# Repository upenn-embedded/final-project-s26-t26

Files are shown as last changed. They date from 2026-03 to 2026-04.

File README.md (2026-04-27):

Review Assignment Due Date (https://classroom.github.com/a/-Acvnhrq)

# Final Project

**Team Number:** Team 12

**Team Name:** AAA Battery

| Team Member Name | Email Address |
| --- | --- |
| Abhay Agarwal | abhaya@seas.upenn.edu  |
| Ashwin Ranjan | aranjan@seas.upenn.edu |
| Arnuv Batra | avbatra@seas.upenn.edu |

**GitHub Repository URL:** https://github.com/upenn-embedded/final-project-s26-t26.git

**GitHub Pages Website URL:** [for final submission]*

## Final Project Proposal

### 1. Abstract

Our project is a dual-axis solar tracker that automatically orients a solar panel toward the brightest light source and maximizes the energy harvested from it. Four light sensors detect the sun's direction, two servos aim the panel, and an MPPT algorithm tunes a buck converter to extract peak power. An ESP32 streams data to a live web dashboard. The system demonstrates measurable efficiency gains over a fixed panel.

### 2. Motivation

Fixed solar panels lose significant energy throughout the day as the sun moves across the sky - often capturing only 60–70% of available energy compared to a panel that tracks the sun. Adding MPPT further increases efficiency by ensuring the panel operates at optimal voltage regardless of changing light and temperature conditions.

This project is interesting as it will combine analog sensing, real-time control, power electronics, and IoT on the ATMega. The result is a fully functional miniature solar energy system that is optimized to maximize power output.

### 3. System Block Diagram

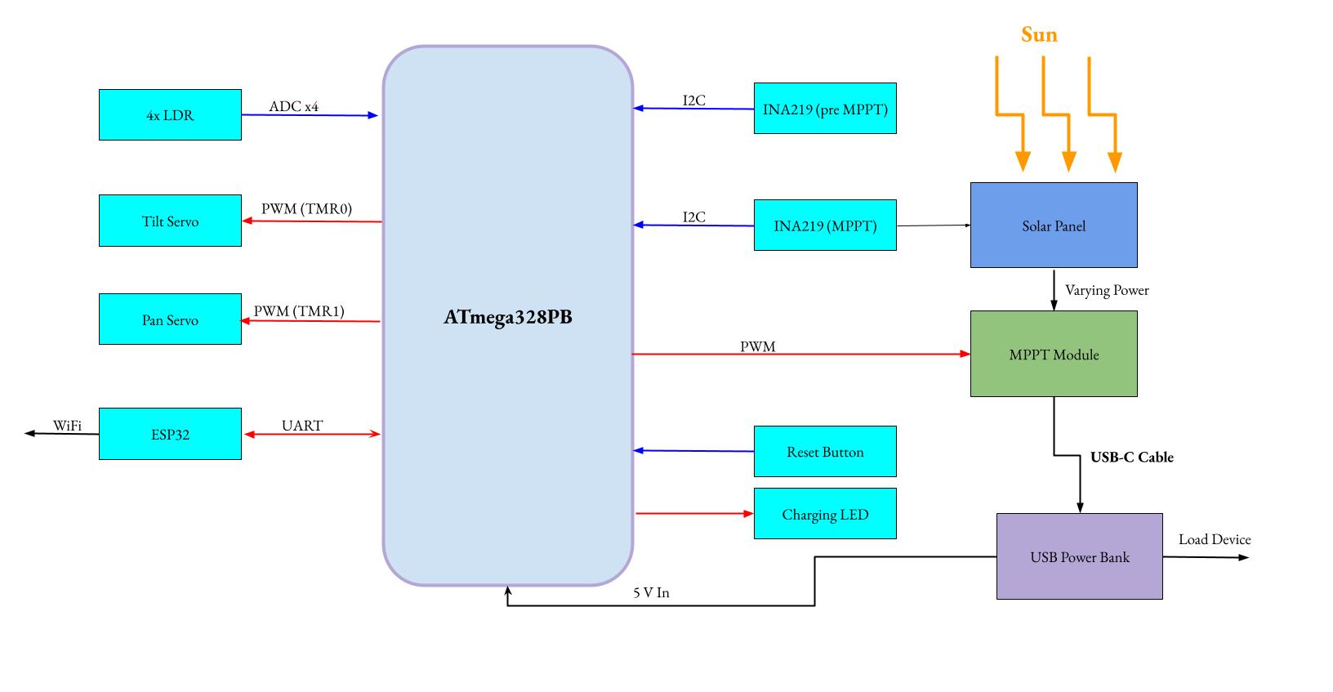
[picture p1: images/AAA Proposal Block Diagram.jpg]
System Block Diagram


### 4. Design Sketches

The LDR quadrant divider is the most critical design feature — a small cross-shaped wall between the four LDRs that creates shadow differences when the panel is off-angle, enabling the tracking algorithm to determine direction.
The pan-tilt bracket and base enclosure will both be 3D-printed, allowing us to customize the mount to fit our specific solar panel and servo arrangement.

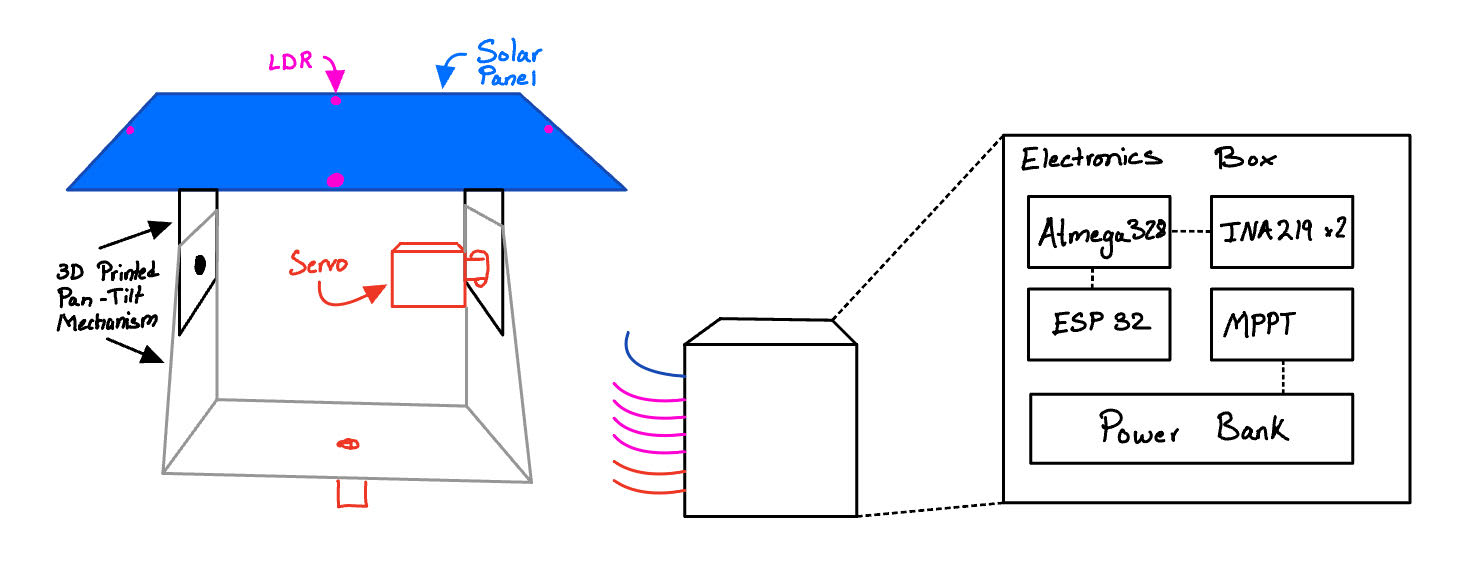
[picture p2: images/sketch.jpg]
Design Sketch


### 5. Software Requirements Specification (SRS)

**5.1 Definitions, Abbreviations**

Here, you will define any special terms, acronyms, or abbreviations you plan to use for hardware

LDR = light dependent resistor

MPPT = Maximum Power Point Tracking (for solar panels, basically constantl adjusting to optimize the voltage/current delivered for maximum power output)

**5.2 Functionality**

| ID | Description |
| --- | --- |
| SRS-01 | The system will sample the 4 LDRs via the ADC at a minimum frequency of 10 Hz. |
| SRS-02 | The firmware will implement a deadband filter algorithm to prevent servo jitter when the calculated light intensity error between opposing LDRs is below a certain threshold. |
| SRS-03 | The system will update the IoT dashboard without major latency (<3 seconds) with current tracking status, MPPT values, and error margins. This will be achieved with a ESP32 coprocessor acting solely as a serial-to-Wi-Fi bridge. |
| SRS-04 | The MCU will utilize hardware timers to generate a stable 50Hz PWM signal for servo actuation without blocking the main execution loop. |
| SRS-05 | Upon a physical button press interrupt, the system will reset the servos to a default home position within 2 seconds. |

### 6. Hardware Requirements Specification (HRS)

**6.1 Definitions, Abbreviations**

Here, you will define any special terms, acronyms, or abbreviations you plan to use for hardware

**6.2 Functionality**

| ID | Description |
| --- | --- |
| HRS-01 | The solar tracking mechanism will physically rotate at least 45 degrees horizontally (pan) and 45 degrees vertically (tilt). |
| HRS-02 | The LDRs accurately capture the difference in light between specific locations on the panel, which is then used to adjust the panel tilt and pan accordingly. |
| HRS-03 | An off-the-shelf MPPT module OR our own custom hardware using a buck/boost converter + PWM from the ATMega will safely regulate the charging voltage from the solar panel to the energy storage system. |
| HRS-04 | The system should charge a battery bank via USB-C, and be able to clearly show whether power is being generated via an LED. |

### 7. Bill of Materials (BOM)
What major components do you need and why? Try to be as specific as possible.:

We need the 2 processors (ATMega and ESP 32). The ATMega is for general communication and interfacing and will be where our computing is done. The ESP32 serves as a port to serve the data we recieve, after processing, to the cloud via wifi. 

We use 4 LDRs to take brightness readings at each corner, and for each of them we read the current that passes through them as a measure of how bright/dim the area is, so we can angle our solar panel accordingly. 

The solar panel is used to actually capture power, and it's mounted on 2 micro stepper motors to control its pan (horizontal) and tilt (vertical) axes. 

A current/voltage sensor is used to read the output power of the solar panel, and the power bank is used to store the generated electricity. 

The details of all these can be found in the sheet below.

[BOM Sheet](https://docs.google.com/spreadsheets/d/1A1eUAg9dwYdbk0ykns5I-RBsm5lOC9emmNqb9aPvp44/edit?usp=sharing)

### 8. Final Demo Goals

A movable desk lamp will simulate the sun. We move the lamp to different positions and the panel visibly tracks it in real time. A laptop next to the device will display the live web dashboard showing power output and panel orientation.
The main constraints are WiFi access in the lab for the ESP32 dashboard and a power outlet for the desk lamp. The device itself runs on its solar panel and battery.

### 9. Sprint Planning

| Milestone  | Functionality Achieved | Distribution of Work |
| --- | --- | --- |
| Sprint #1  | Finalize BOM, order parts, and begin 3D printing the gimbal/baffle. Set up the bare-metal C toolchain. Write and test the ADC polling and PWM timer code. Connect the servos and test movement. | Arnuv: BOM finalization, 3D print gimbal/baffle. Abhay: ADC polling & LDR voltage divider setup, toolchain config. Ashwin: PWM timer drivers & servo connection/testing. |
| Sprint #2  | Implement the LDR-based tracking algorithm with deadband filtering and verify servo response to differential light readings. Begin MPPT module wiring and validate solar panel charging into the battery bank. Set up UART communication between ATmega and ESP32 and confirm serial data passthrough. Start scaffolding the web dashboard on the ESP32 side. | Arnuv: MPPT module wiring, solar panel integration, charging validation. Abhay: UART bridge between ATmega & ESP32, begin ESP32 dashboard scaffolding. Ashwin: Tracking algorithm with deadband filter, servo closed-loop testing. |
| MVP Demo | Integrate LDR inputs with servo outputs to achieve basic tracking. Wire the MPPT module for basic charging. Integrate the I2C current sensors. Write the UART bridge firmware and establish the ESP32 web dashboard. | Arnuv: I2C INA219 sensor integration, mechanical assembly refinement, home-position button interrupt. Abhay: Live dashboard displaying tracking status & MPPT values. Ashwin: Full tracking loop integration. |
| Final Demo | Final hardware integration, code optimization, and rigorous testing for the final demonstration. | All: End-to-end system testing, debugging, demo prep. Arnuv: Mechanical fit & finish, LED power indicator integration. Abhay: Dashboard polish & latency validation. Ashwin: Tracking accuracy tuning & code cleanup. |

**This is the end of the Project Proposal section. The remaining sections will be filled out based on the milestone schedule.**

## Sprint Review #1

### Last week's progress

This week we built a simplified single-axis solar tracker demo to validate our core tracking algorithm before integrating into the full dual-axis system. We wrote the code in demo.c and pushed it to the repo.
The demo uses two LDRs connected to PC0 and PC1 to sense light direction. We configured Timer1 to generate 50Hz PWM on PB1 for servo control. The tracking algorithm compares the two LDR readings and moves the servo toward the brighter side. We also implemented a deadband filter to prevent the servo from jittering when the light levels are nearly equal.

During development we ran into a few issues. The board kept resetting whenever the servo moved, which we traced to the servo drawing too much current and causing a voltage drop.

Once we fixed that, we discovered the servo was drifting more in one direction even when the light was centered. This was because our two LDRs have slightly different responses, so we added UART printing to read the raw ADC values. Next time we will calculate a calibration offset to add to our code

### Current state of project
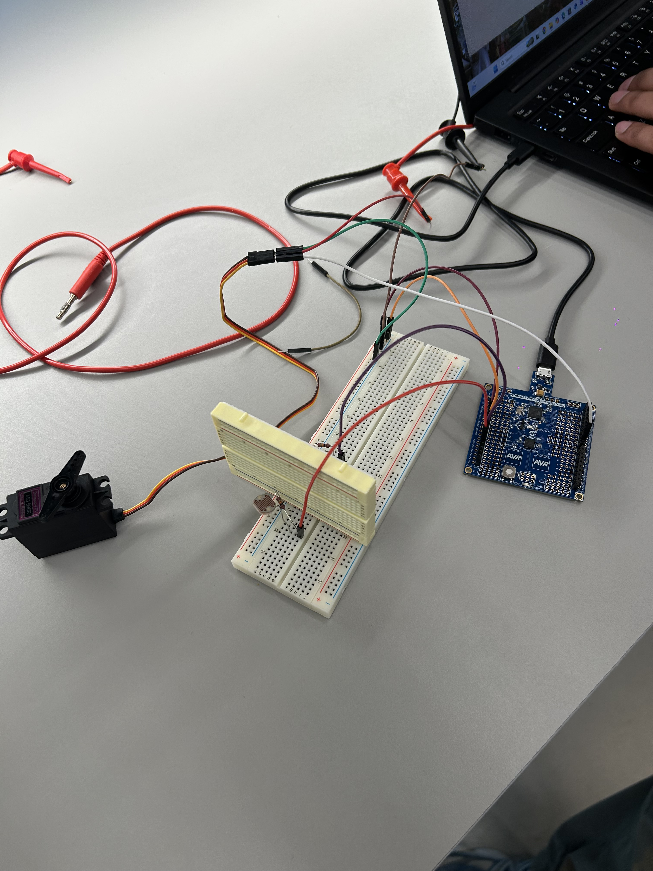
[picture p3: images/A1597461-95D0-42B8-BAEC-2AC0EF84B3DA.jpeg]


The single-axis tracking demo is working. The servo successfully follows a light source using two LDRs. This validates our tracking algorithm and servo control code, which we can now duplicate for the second axis. The 3D printed gimbal mount is being designed. We have also ordered the needed parts.

### Next week's plan

Abhay will set up the INA219 sensors and ESP32 communication, around 5 hours. Done when sensor data displays on the ESP32.

Ashwin will add the second servo and tune the tracking, around 4 hours. Done when the panel tracks light in both axes smoothly.

Arnuv will 3D print the gimbal mount and LDR divider, around 6 hours. Done when everything is mounted and moves freely.

## Sprint Review #2

### Last week's progress

Abhay completed the INA219 current/voltage sensing setup. The INA219 is now communicating over I2C and providing accurate power readings from the solar panel. The driver code has been written and pushed to the repo.

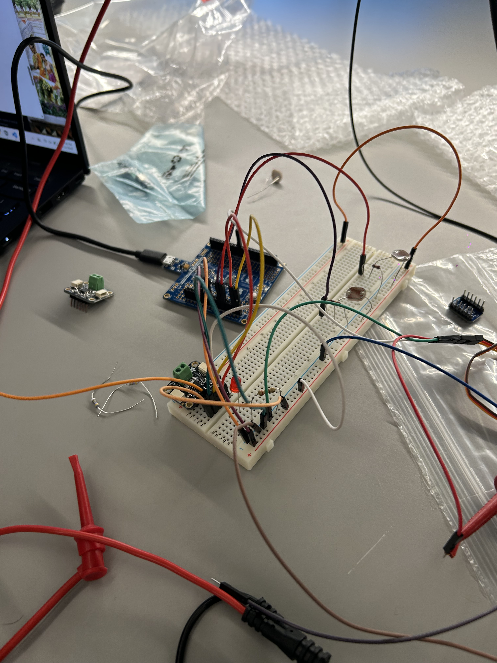
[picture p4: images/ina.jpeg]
INA219 Sensor


Ashwin got the ESP32 Feather working and set up a local web server that pulls all sensor data for the live dashboard. He also sent off the prints for the remaining mechanical housing parts.

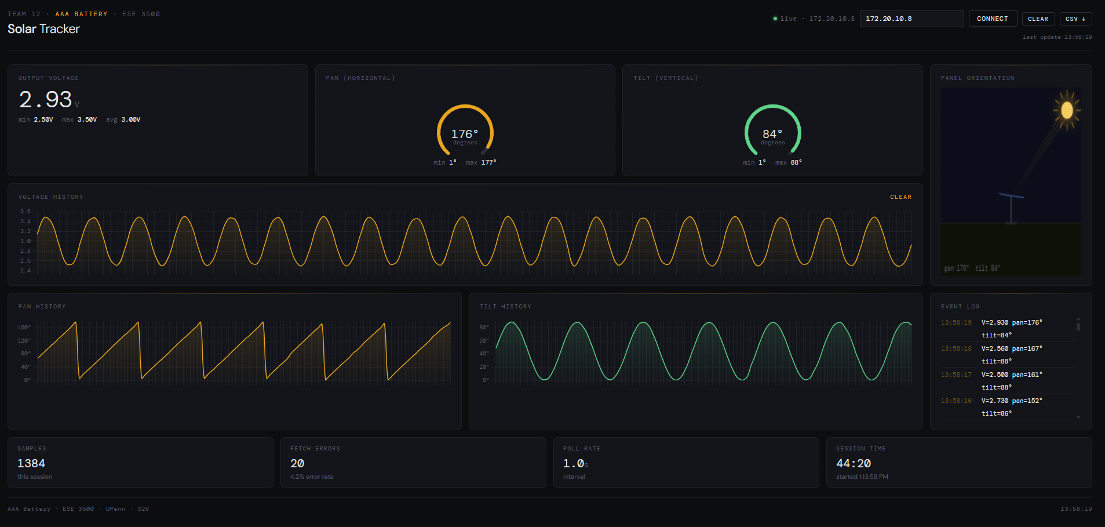
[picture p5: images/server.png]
Web Server Dashboard


Arnuv printed the mechanical parts for the gimbal and is assembling the full pan-tilt mechanism with the servos mounted. He also CADed and printed a solar panel mount.

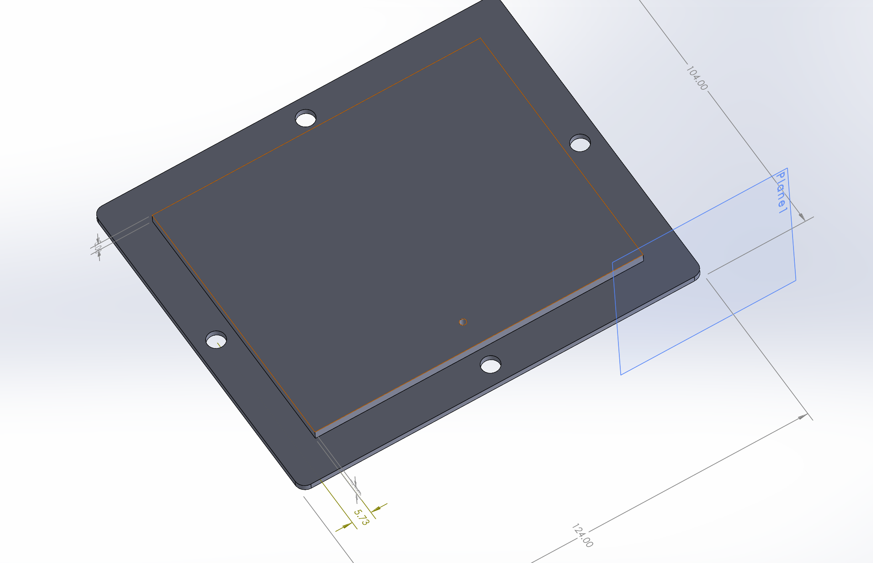
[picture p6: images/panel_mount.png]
Solar Panel Mount


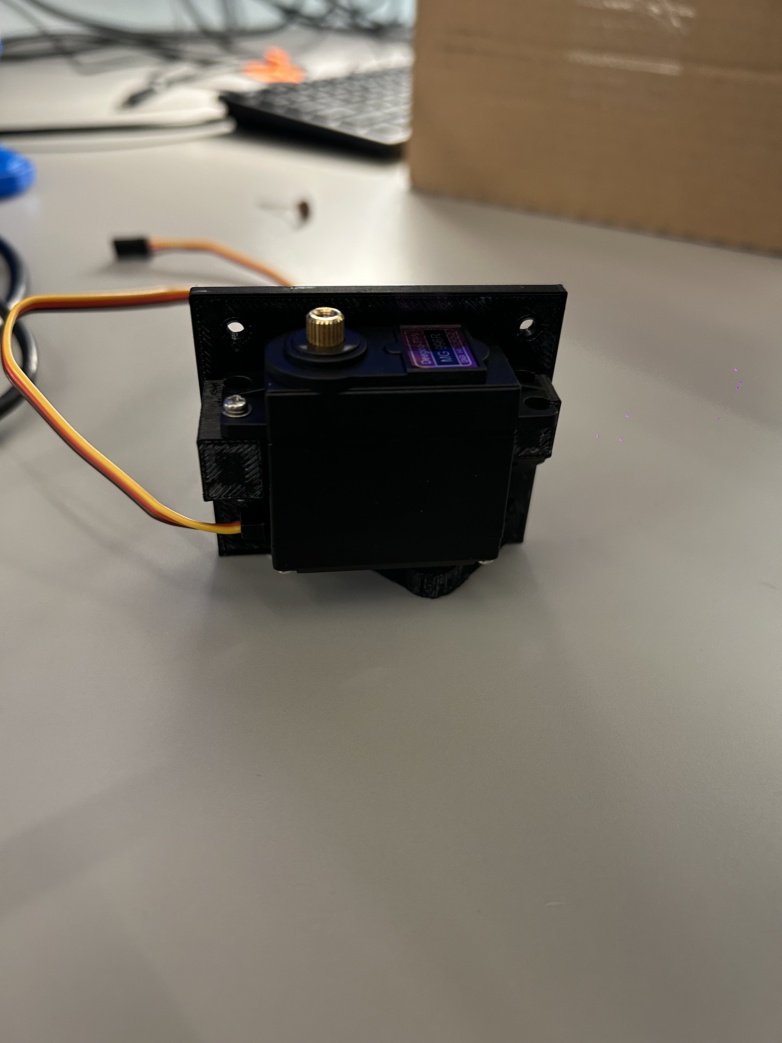
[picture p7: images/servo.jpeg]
Servo Assembly


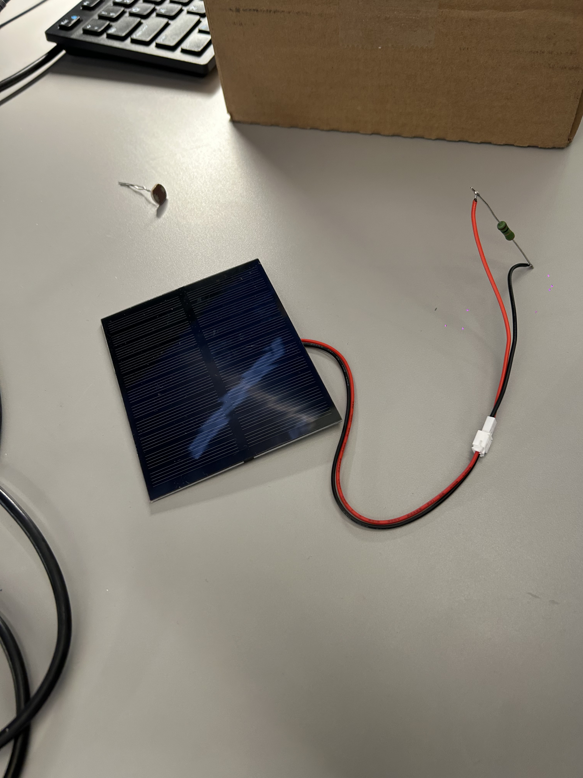
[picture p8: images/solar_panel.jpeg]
Solar Panel


### Current state of project

The core sensing and data pipeline is coming together. The INA219 is reading solar panel power output, the ESP32 is hosting a live dashboard over Wi-Fi, and the mechanical gimbal is being assembled with the 3D-printed parts. The main integration work remaining is connecting the ATmega tracking loop to the ESP32 dashboard via UART and mounting the solar panel on the completed gimbal.

### Next week's plan

Abhay will integrate the INA219 readings into the UART data stream to the ESP32, around 4 hours. Done when live power data appears on the web dashboard.

Ashwin will finalize the full tracking loop integrating both axes with the ESP32 data display, around 5 hours. Done when the dashboard shows real-time tracking status and power output.

Arnuv will complete the mechanical assembly and mount the solar panel and LDR divider onto the gimbal, around 5 hours. Done when the full system is physically assembled and the panel can move freely on both axes.

## MVP Demo

### 1. System block diagram & hardware implementation

System Block Diagram

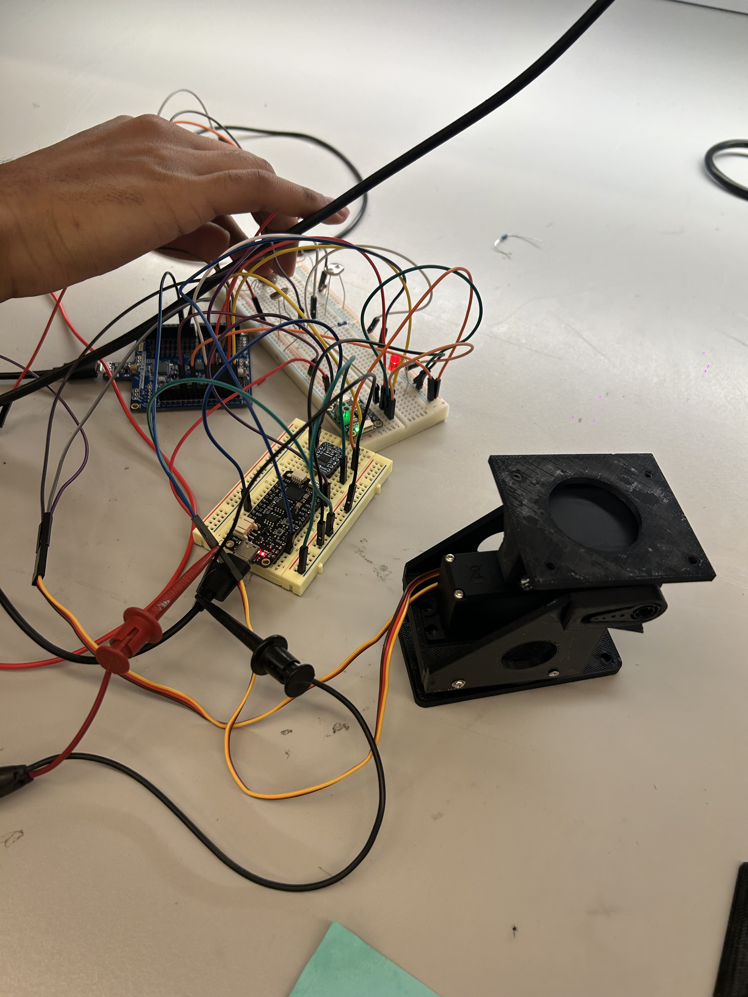
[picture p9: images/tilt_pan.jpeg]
Assembled pan/tilt tracker


The ATmega328PB is the main MCU. It runs the tracking loop, reads the four LDRs through its ADC, drives both servos with hardware-timer PWM, and talks to the INA219 over I2C. It then ships the full telemetry packet (voltage, current, power, pan, tilt) up to the ESP32 Feather over UART. The Feather acts as a serial-to-Wi-Fi bridge and parses the UART frames and hosts a local HTTP server that shows the latest readings. 

Power-wise, the solar panel goes through an INA219 sensor, then into the MPPT/buck stage, then into a USB-C power bank. A "power OK" LED will be wired off the panel-side rail to show when the panel is generating.

### 2. Firmware implementation

#### Application logic (ATmega, [Code/main.c](Code/main.c))

- Main loop samples four LDRs via ADC, computes horizontal and vertical error from opposing pairs, applies a deadband, and nudges the pan/tilt servo targets. Servo duty cycles are written directly to the Timer1 compare registers so the 50 Hz PWM never blocks the main loop.
- Polls the INA219 every loop iteration and packs voltage/current/power plus current pan/tilt into a CSV line sent over UART at 9600 baud.
- Home-position button routed to an external interrupt pin, so the ISR sets a flag that the main loop picks up to drive both servos back to center.

#### ATMega Code

- [Code/i2c.c](Code/i2c.c) / [Code/i2c.h](Code/i2c.h) — I2C master driver for the ATmega: start/stop, byte read/write, repeated-start, no Arduino Wire dependency.
- [Code/ina219.c](Code/ina219.c) / [Code/ina219.h](Code/ina219.h) — INA219 driver built on top of our I2C driver. Configures the calibration register and gets voltage and current readings.
- [Code/uart.c](Code/uart.c) / [Code/uart.h](Code/uart.h) — UART TX/RX driver used for debug prints and the ESP32 server.
- [Code/demo.c](Code/demo.c) — the Sprint #1 single-axis validation demo that we generalized into the dual-axis tracker in [Code/main.c](Code/main.c).

#### ESP32 Code ([Code/ese3500_uart.ino](Code/ese3500_uart.ino))

- Reads the UART CSV frames and outputs a JSON. Also serves the server [index.html](index.html).

### 3. Demo

> **https://drive.google.com/file/d/1Zr529B0K1XDM-7jDKDU-3Q6FYsO6Z7r6/view?usp=sharing**

Live demo flow: point a desk lamp at the panel → the gimbal tracks toward it on both axes → the dashboard updates voltage, current, and power in real time.

### 4. SRS status & validation

<!-- markdownlint-disable MD060 -->

| ID | Description | Status | Validation |
| --- | --- | --- | --- |
| SRS-01 | Sample 4 LDRs via ADC at >=10 Hz | Achieved | Main loop has an inbuilt delay of 100ms, so each LDR samples at 10 Hz. |
| SRS-02 | Deadband filter to prevent servo jitter | Achieved | With panel centered, servos hold still; logged UART error values stay inside the deadband. |
| SRS-03 | IoT dashboard updates with < 3 s latency | Achieved | Dashboard polls the ESP32 server data at 1 Hz; measured end-to-end UART-to-dashboard lag is under 3s |
| SRS-04 | Hardware-timer 50 Hz PWM, non-blocking | Achieved | Scoped PB1/PB2 PWM outputs - stable 20 ms period, main loop continues executing during PWM.|
| SRS-05 | Button interrupt resets servos to home within 2 s | Achieved | Button wired to external-interrupt pin; servos return to center on press, well under 2 s.  |

<!-- markdownlint-enable MD060 -->

**How we collected the data:** GPIO-toggle + oscilloscope for ADC and PWM timing (SRS-01, SRS-04); live UART logs captured on the laptop for deadband and latency checks (SRS-02, SRS-03); timer on repeated button presses for SRS-05.

### 5. HRS status & validation

<!-- markdownlint-disable MD060 -->

| ID | Description | Status | Validation |
| --- | --- | --- | --- |
| HRS-01 | Physical rotation >=45 deg pan and >=45 deg tilt | Achieved | Both axes exceed 45 degrees visually - pan is 180 degrees of motion and tilt is ~80. |
| HRS-02 | LDRs capture light differences for tracking | Achieved | Moved a phone flashlight across the LDR array and logged raw ADC values over UART; opposing pairs diverge cleanly.|
| HRS-03 | MPPT / buck-boost regulating charging from the panel | Not achieved | Module is wired on the bench but MPPT tuning against the real panel is still open. |
| HRS-04 | USB-C battery-bank charging with LED power indicator | Partial | LED is mounted; remaining work is wiring the solar-panel rail through to the USB-C output. |

<!-- markdownlint-enable MD060 -->

**How we collected the data:** visual measurement on the physical gimbal (HRS-01); LDR raw ADC logs streamed over UART and cross-checked against the dashboard (HRS-02); INA219 voltage/current on the dashboard while the panel is under lamp (feeds into HRS-03 validation for Final Demo).

### 6. Remaining elements to complete the project

- **Mechanical enclosure** — enclosure base for the electronics is printing but needs fit-and-finish (cable routing, lid, button cutout).
- **GUI / web portal** — the dashboard in [index.html](index.html) is live and charting voltage/current/power/pan/tilt; remaining polish is a dedicated history chart for power and an MPPT efficiency plot once HRS-03 is done.
- **Power path** — finish HRS-04 by routing the regulated panel output through the USB-C charger IC and wiring the "power OK" LED off that rail.
- **MPPT tuning** — sweep the buck converter duty cycle and log power to find the peak (HRS-03).

### 7. Riskiest part remaining

**MPPT (HRS-03).** The tracking, sensing, and dashboard are all solved. The riskiest piece left is getting the buck-converter + MPPT loop to actually hold the panel at its maximum-power point under changing light without oscillating or stalling the panel.

### 8. De-risking plan

- Start with a fixed duty-cycle sweep logged through the INA219, so we can plot a P-V curve for our panel under the lamp and confirm the MPPT is converging to the real peak.
- Implement perturb-and-observe in small duty-cycle steps with a dwell time longer than the INA219 conversion time to avoid chasing noise.
- Fall back to an off-the-shelf MPPT module (already in the BOM) if our custom loop is unstable by the week before Final Demo — this is the explicit "OR" in HRS-03.
- Keep the panel → INA219 → dashboard path as a bench oscilloscope for the MPPT loop, so any regression is visible in real time.

### 9. Questions / help from the teaching team
N/A

## Final Report

Don't forget to make the GitHub pages public website!
If you’ve never made a GitHub pages website before, you can follow this webpage (though, substitute your final project repository for the GitHub username one in the quickstart guide):  [https://docs.github.com/en/pages/quickstart](https://docs.github.com/en/pages/quickstart)

### 1. Video

### 2. Images

### 3. Results

#### 3.1 Software Requirements Specification (SRS) Results

| ID | Description | Validation Outcome |
| --- | --- | --- |
| SRS-01 | The IMU 3-axis acceleration will be measured with 16-bit depth every 100 milliseconds +/-10 milliseconds. | Confirmed, logged output from the MCU is saved to "validation" folder in GitHub repository. |

#### 3.2 Hardware Requirements Specification (HRS) Results

| ID | Description | Validation Outcome |
| --- | --- | --- |
| HRS-01 | A distance sensor shall be used for obstacle detection. The sensor shall detect obstacles at a maximum distance of at least 10 cm. | Confirmed, sensed obstacles up to 15cm. Video in "validation" folder, shows tape measure and logged output to terminal. |
| | | |

### 4. Conclusion

## References

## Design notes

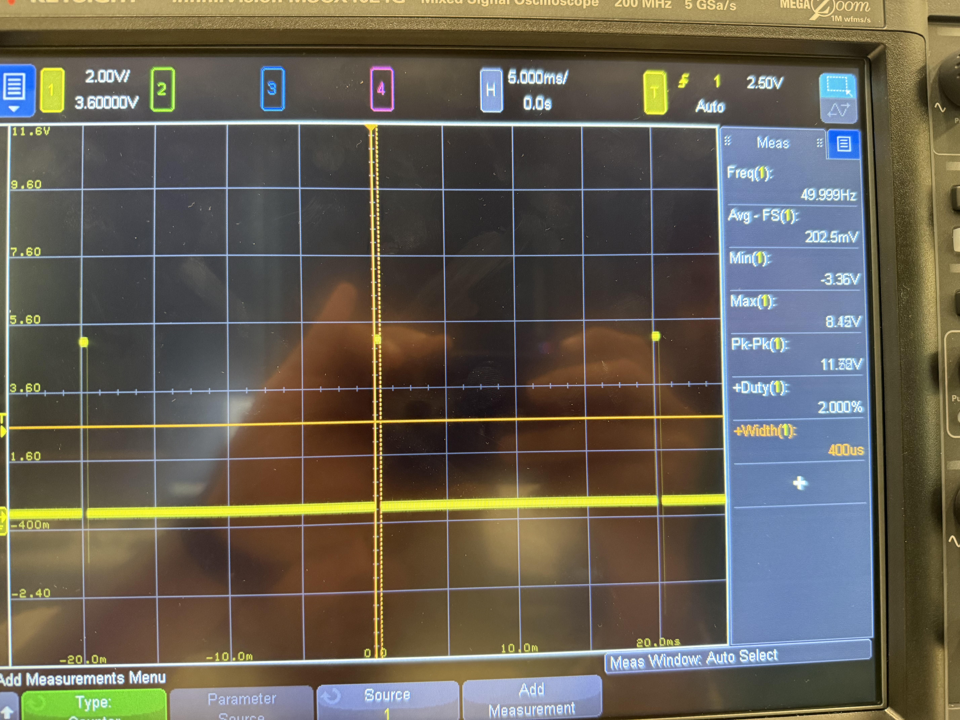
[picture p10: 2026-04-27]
images/min_duty_cycle.jpg

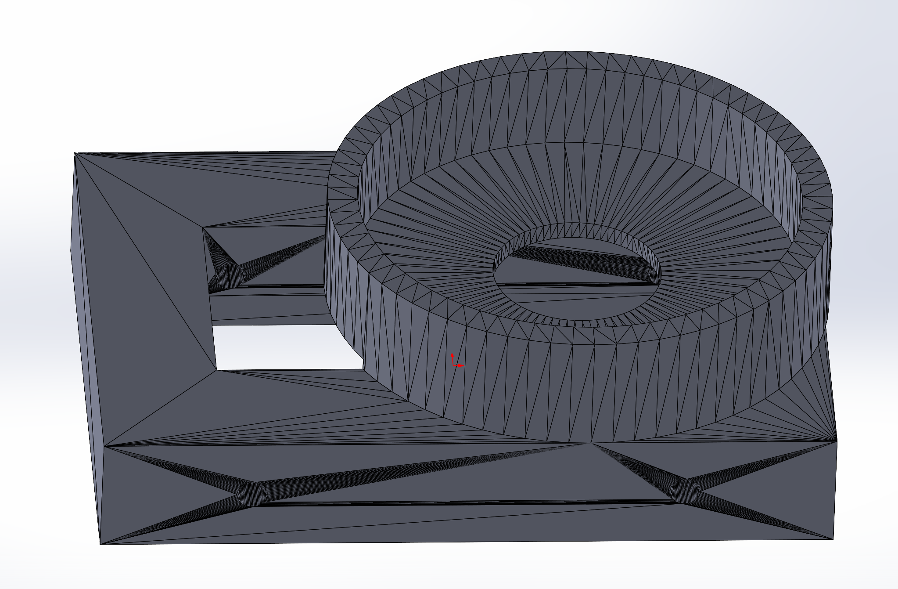
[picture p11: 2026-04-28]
docs/images/cad1.png

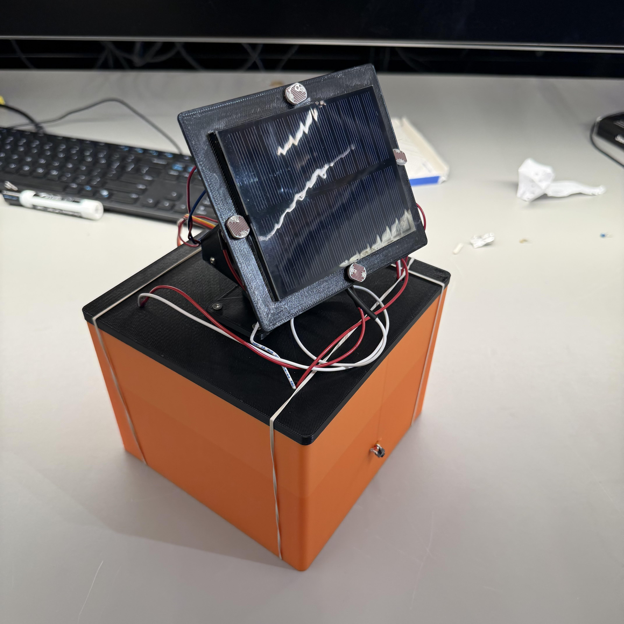
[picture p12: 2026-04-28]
images/final_project.jpg

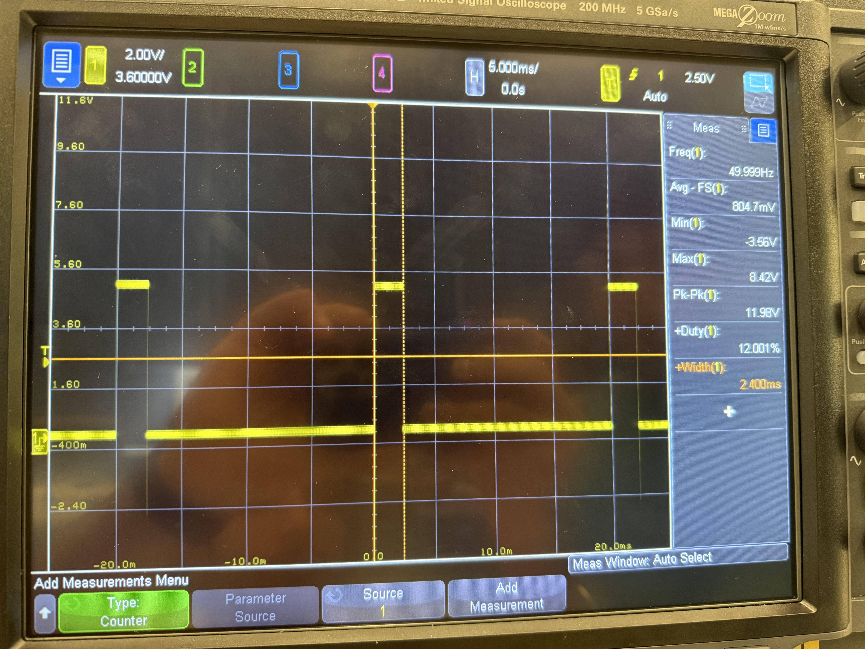
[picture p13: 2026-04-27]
images/max_duty_cycle.jpg

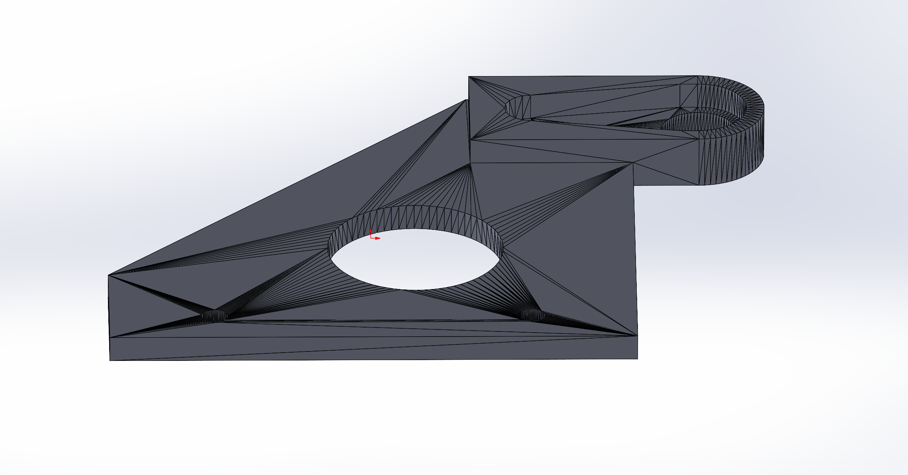
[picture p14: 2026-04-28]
docs/images/cad3.png

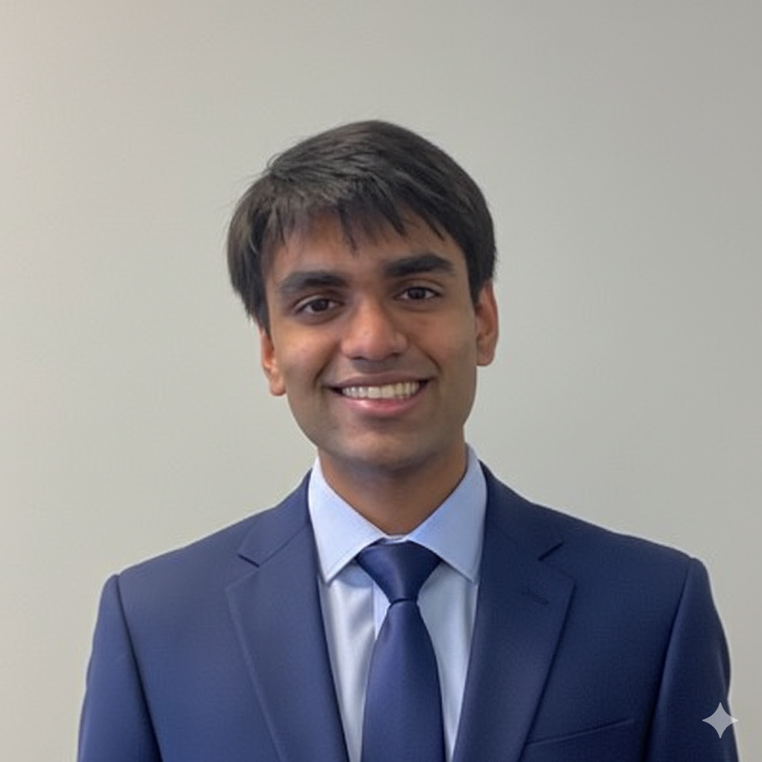
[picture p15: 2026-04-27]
images/Abhay Agarwal Headshot.png

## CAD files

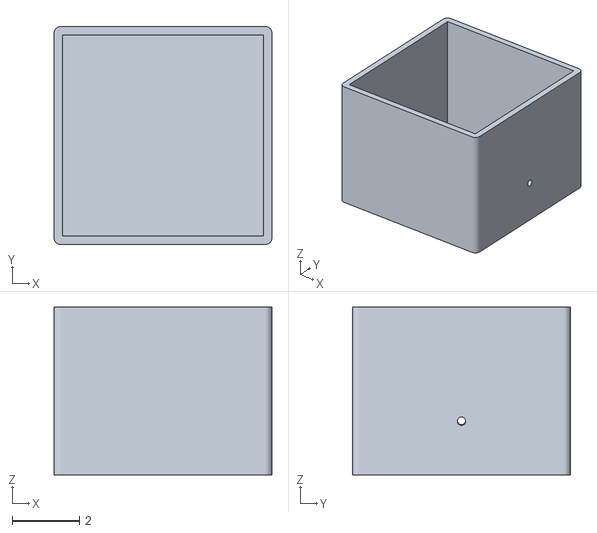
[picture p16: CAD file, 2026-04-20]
CAD/ESE 3500 Enclosure.stl
6.50 x 6.50 x 5.00

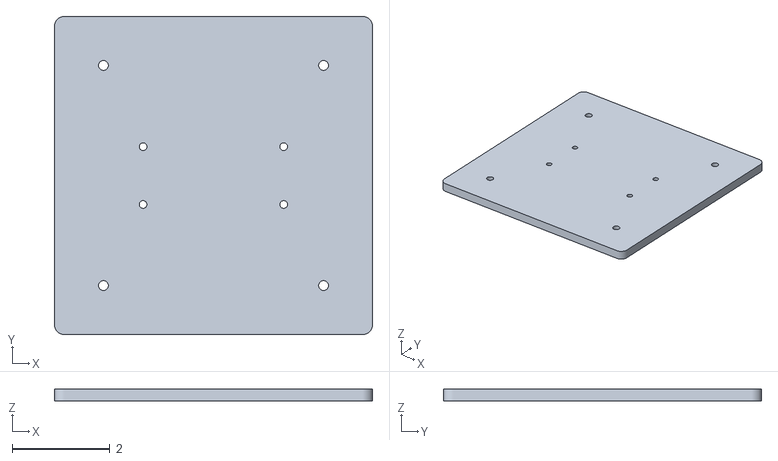
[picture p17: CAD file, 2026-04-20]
CAD/ESE 3500 Enclosure Lid.stl
6.50 x 6.50 x 0.25

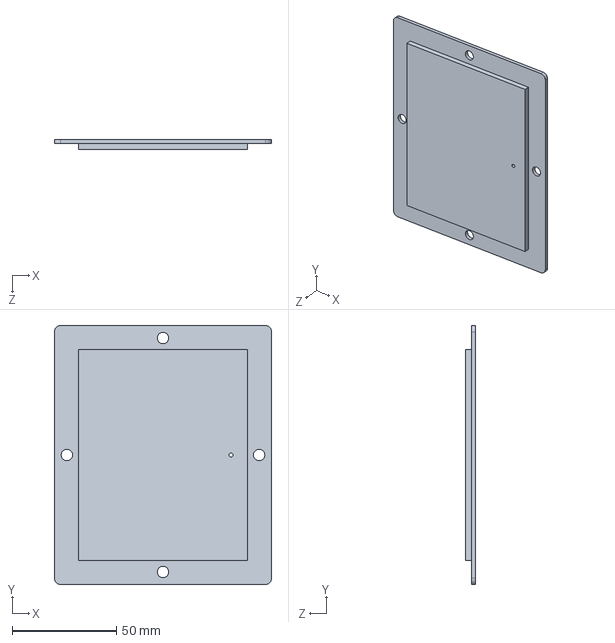
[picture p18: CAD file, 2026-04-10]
CAD/ESE 3500 Solar Mounting Plate REV 1.SLDPRT
104.0 x 124.0 x 5.00 mm

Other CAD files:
CAD/ESE 3500 Solar Mounting Plate.STL

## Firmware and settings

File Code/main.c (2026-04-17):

#define F_CPU 16000000UL
#include <avr/io.h>
#include <avr/interrupt.h>
#include <util/delay.h>
#include <stdio.h>
#include "uart.h"
#include "i2c.h"
#include "ina219.h"

// ============== SETTINGS ==============
#define DEADBAND    10
#define STEP_SIZE   200

// Tilt servo (PB1)
#define TILT_MIN    1200
#define TILT_MAX    2400
#define TILT_MID    1800

// Pan servo (PB2)
#define PAN_MIN     800
#define PAN_MAX     4800
#define PAN_MID     2800

// ============== LDR CHANNELS ==============
#define LDR_TOP     0
#define LDR_BOTTOM  1
#define LDR_EAST    2
#define LDR_WEST    3

// ============== GLOBAL VARIABLES ==============
uint16_t tiltPos = TILT_MID;
uint16_t panPos  = PAN_MID;

// ============== SETUP FUNCTIONS ==============
void setupADC(void) {
    ADMUX  = (1 << REFS0);
    ADCSRA = (1 << ADEN) | (1 << ADPS2) | (1 << ADPS1) | (1 << ADPS0);
}

void setupServos(void) {
    DDRB |= (1 << PB1) | (1 << PB2);

    TCCR1A = (1 << COM1A1) | (1 << COM1B1) | (1 << WGM11);
    TCCR1B = (1 << WGM13)  | (1 << WGM12)  | (1 << CS11);

    ICR1  = 39999;
    OCR1A = TILT_MID;
    OCR1B = PAN_MID;
}

// ============== HELPER FUNCTIONS ==============
uint16_t readADC(uint8_t channel) {
    ADMUX = (ADMUX & 0xF0) | (channel & 0x0F);
    ADCSRA |= (1 << ADSC);
    while (ADCSRA & (1 << ADSC));
    return ADC;
}

void moveTilt(uint16_t position) {
    if (position < TILT_MIN) position = TILT_MIN;
    if (position > TILT_MAX) position = TILT_MAX;
    OCR1A   = position;
    tiltPos = position;
}

void movePan(uint16_t position) {
    if (position < PAN_MIN) position = PAN_MIN;
    if (position > PAN_MAX) position = PAN_MAX;
    OCR1B  = position;
    panPos = position;
}

void goHome(void) {
    moveTilt(TILT_MIN);   // Tilt to minimum position
    movePan(PAN_MID);     // Pan to centre position
}

uint8_t tiltToDeg(uint16_t pos) {
    return (uint8_t)((uint32_t)(pos - TILT_MIN) * 180 / (TILT_MAX - TILT_MIN));
}

uint8_t panToDeg(uint16_t pos) {
    return (uint8_t)((uint32_t)(pos - PAN_MIN) * 180 / (PAN_MAX - PAN_MIN));
}

// ============== MAIN PROGRAM ==============
int main(void) {
    // I2C pins - no pull-up (external)
    DDRC  &= ~((1 << PC4) | (1 << PC5));
    PORTC &= ~((1 << PC4) | (1 << PC5));

    // PD2 home button - input, no internal pull-up (external pull-up resistor)
    DDRD  &= ~(1 << PD2);
    PORTD &= ~(1 << PD2);

    setupADC();
    setupServos();
    uart_init();

    _delay_ms(100);
    printf("Starting dual-axis tracker...\n");

    i2c_init();
    ina219_init();

    _delay_ms(1000);

    while (1) {
        // ---- Home button check (active-low, external pull-up on PD2) ----
        if (!(PIND & (1 << PD2))) {
            goHome();
            printf("HOME\n");
            while (!(PIND & (1 << PD2)));  // Wait for release
            _delay_ms(1000);                 // Debounce
            continue;
        }

        // ---- Solar tracking ----
        uint16_t top    = readADC(LDR_TOP);
        uint16_t bottom = readADC(LDR_BOTTOM);
        uint16_t east   = readADC(LDR_EAST);
        uint16_t west   = readADC(LDR_WEST);

        int16_t diffV = top - bottom;
        int16_t diffH = east - west;

        if      (diffV >  DEADBAND) moveTilt(tiltPos - STEP_SIZE);
        else if (diffV < -DEADBAND) moveTilt(tiltPos + STEP_SIZE);

        if      (diffH >  DEADBAND) movePan(panPos - STEP_SIZE);
        else if (diffH < -DEADBAND) movePan(panPos + STEP_SIZE);

        // ---- Power telemetry ----
        uint16_t voltage = ina219_get_voltage_mv();
        int16_t  current = ina219_get_current_ma();
        int32_t  power   = ((int32_t)voltage * current) / 1000;

        uint8_t tiltDeg = tiltToDeg(tiltPos);
        uint8_t panDeg  = panToDeg(panPos);

        printf("V:%u,I:%d,P:%ld,TILT:%u,PAN:%u\n",
               voltage, current, power, tiltDeg, panDeg);

        _delay_ms(100);
    }

    return 0;
}

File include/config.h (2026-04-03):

#ifndef CONFIG_H
#define CONFIG_H

#include <stdint.h>
#include <stdbool.h>

/* ============================================================================
 * SYSTEM CONFIGURATION
 * ============================================================================ */

#define F_CPU 16000000UL  // ATmega328P clock frequency

/* ============================================================================
 * LDR CONFIGURATION (SRS-01)
 * ============================================================================ */

#define LDR_SAMPLE_FREQ_HZ      10      // Minimum 10 Hz sampling
#define LDR_DEADBAND_THRESHOLD  50      // ADC counts for deadband filter (SRS-02)

// ADC channel assignments for LDR quadrant
#define LDR_TOP_LEFT_CH         0       // ADC0 (PC0)
#define LDR_TOP_RIGHT_CH        1       // ADC1 (PC1)
#define LDR_BOTTOM_LEFT_CH      2       // ADC2 (PC2)
#define LDR_BOTTOM_RIGHT_CH     3       // ADC3 (PC3)

/* ============================================================================
 * SERVO CONFIGURATION (SRS-04, HRS-01)
 * ============================================================================ */

#define SERVO_PWM_FREQ_HZ       50      // Standard servo PWM frequency
#define SERVO_PAN_MIN_DEG       0
#define SERVO_PAN_MAX_DEG       180
#define SERVO_TILT_MIN_DEG      0
#define SERVO_TILT_MAX_DEG      90
#define SERVO_HOME_PAN_DEG      90      // Default home position
#define SERVO_HOME_TILT_DEG     45

/* ============================================================================
 * UART CONFIGURATION (SRS-03)
 * ============================================================================ */

#define UART_BAUD_RATE          115200
#define UART_TX_BUFFER_SIZE     128
#define UART_RX_BUFFER_SIZE     64

/* ============================================================================
 * I2C CONFIGURATION
 * ============================================================================ */

#define I2C_CLOCK_HZ            100000  // 100 kHz standard mode
#define INA219_I2C_ADDR         0x40    // Default INA219 address

/* ============================================================================
 * POWER MONITORING CONFIGURATION
 * ============================================================================ */

// Buck-boost regulates solar panel output to 5V for USB charging
#define REGULATED_OUTPUT_MV     5000
#define POWER_LED_PIN           PB0     // LED indicating power generation (HRS-04)

/* ============================================================================
 * TIMING CONFIGURATION
 * ============================================================================ */

#define HOME_RESET_TIMEOUT_MS   2000    // SRS-05: Reset within 2 seconds
#define DASHBOARD_UPDATE_MS     1000    // Update interval for ESP32

#endif // CONFIG_H

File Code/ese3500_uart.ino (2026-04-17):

#include <WiFi.h>
#include <WebServer.h>

const char* SSID     = "Ashwin's iPhone (2)";
const char* PASSWORD = "ashwinshotspot";

WebServer server(80);

float voltage = 0;
int   current = 0;
int   power   = 0;
int   pan     = -1;
int   tilt    = -1;

void handleData() {
  char buf[160];
  snprintf(buf, sizeof(buf),
    "{\"voltage\":%.2f,\"current\":%d,\"power\":%d,\"pan\":%s,\"tilt\":%s}",
    voltage, current, power,
    pan  >= 0 ? String(pan).c_str()  : "null",
    tilt >= 0 ? String(tilt).c_str() : "null");

  server.sendHeader("Access-Control-Allow-Origin", "*");
  server.send(200, "application/json", buf);
}

void setup() {
  Serial.begin(115200);
  delay(3000);
  Serial.println("Booting...");

  Serial1.begin(9600, SERIAL_8N1, 11, -1);

  WiFi.begin(SSID, PASSWORD);
  while (WiFi.status() != WL_CONNECTED) delay(500);
  Serial.print("IP: ");
  Serial.println(WiFi.localIP());

  server.on("/data", HTTP_GET, handleData);
  server.begin();
}

void loop() {
  if (Serial1.available()) {
    String line = Serial1.readStringUntil('\n');
    line.trim();

    int v, i, ti, pa;
    long p;
    // Updated to parse: V:5000,I:100,P:500,TILT:45,PAN:90
    if (sscanf(line.c_str(), "V:%d,I:%d,P:%ld,TILT:%d,PAN:%d", &v, &i, &p, &ti, &pa) == 5) {
      voltage = v / 1000.0;
      current = i;
      power   = (int)(voltage * i);
      tilt    = ti;
      pan     = pa;
      Serial.printf("V:%.2fV  I:%dmA  P:%dmW  TILT:%d°  PAN:%d°\n", voltage, current, power, tilt, pan);
    }
  }

  server.handleClient();
}

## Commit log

2026-03-15 Add BOM Link
2026-03-15 Finished BOM response.
2026-03-15 expanded on BOM
2026-04-03 Current State of Project - Sprint 1
2026-04-10 Added CAD files.
    [ESE 3500 Solar Mounting Plate REV 1.SLDPRT, ESE 3500 Solar Mounting Plate.STL]
2026-04-15 updated server to include power/current
2026-04-15 Added PAN and also changed the format for UART
2026-04-15 Added the Arduino UART Code
2026-04-17 Added PAN servo
2026-04-17 Added PAN UART
2026-04-17 Added Home Button
2026-04-20 Added Enclosure CAD files.
    [ESE 3500 Enclosure Lid.stl, ESE 3500 Enclosure.stl]
2026-04-20 Added wiring diagram.
2026-04-28 added cad imageS
